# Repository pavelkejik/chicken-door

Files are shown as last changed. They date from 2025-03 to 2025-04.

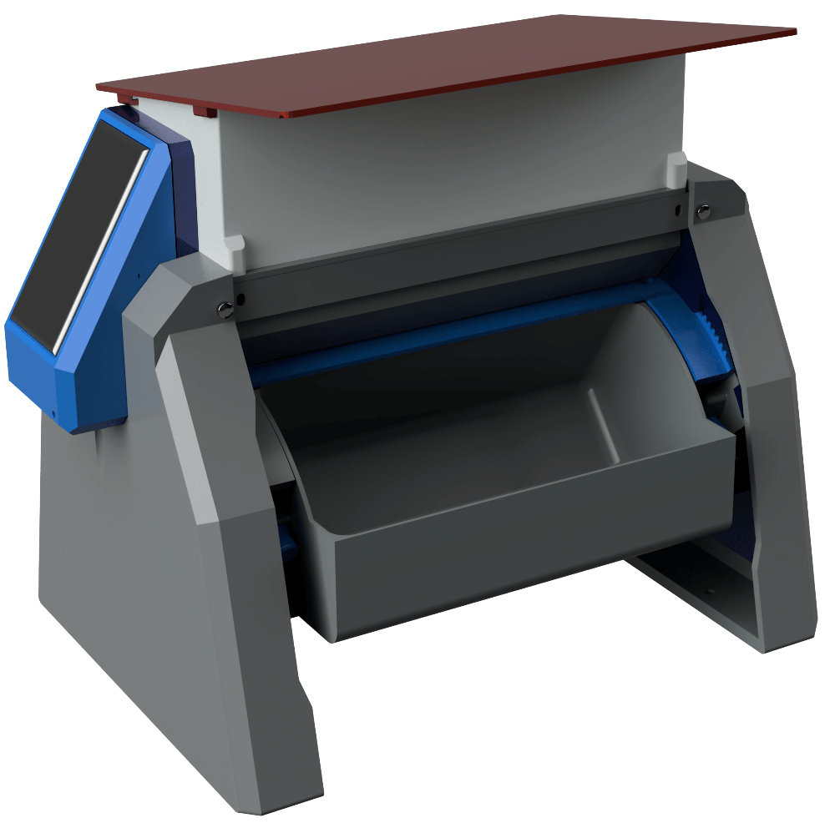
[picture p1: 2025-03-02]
web/src/assets/feeder.PNG

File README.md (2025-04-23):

# 🐔 Automated Chicken Coop Ecosystem  
_A modular IoT platform for stress-free backyard chicken keeping_

## Contents
1. [Project Overview](#project-overview)  
2. [Core Features](#core-features)  
3. [System Architecture](#system-architecture)  
4. [Hardware](#hardware)  
   1. [Chicken Door (Gateway)](#chicken-door-gateway)  
   2. [Accessories](#accessories)  
5. [Communication & APIs](#communication--apis)  
6. [Safety & Reliability](#safety--reliability)  
7. [Getting Started](#getting-started)  
8. [MQTT Quick Reference](#mqtt-quick-reference)  
9. [Roadmap](#roadmap)  

---

## Project Overview
The project automates everyday coop duties by combining a **smart sliding door**, a set of battery-powered **accessories** (feeder, camera, …) and a modern web UI.  
The door acts as the **gateway**: it drives the motor, pairs with accessories over low-power **ESP-NOW**, exposes a local **Web UI + HTTP API**, and bridges everything to standard **MQTT** and optional **Modbus RTU** for seamless Home-Assistant integration.

---

## Core Features
| Area | Highlights |
|---|---|
|Automation|• Auto-open/close by **sunrise/sunset** (astronomical) or **ambient light** plus configurable offsets  <br>• Full manual override via button, Web UI, MQTT, or Modbus|
|Safety|• Encoder-based position tracking, upper/lower limit calibration, soft-start/stop  <br>• Stall/over-current detection, timeout watchdog, emergency-stop state|
|Connectivity|• Wi-Fi STA/AP, **ESP-NOW** for accessories (1 km LR)  <br>• MQTT (via configurable `base_topic`), HTTP/REST, captive portal|
|Updates|• **OTA** firmware & file-system updates for door *and* every paired accessory through ESP-NOW|
|Accessories|• **Smart Feeder** – scheduled or weight-based servings  <br>• **Coop Camera** – still images on demand  <br>_Add your own!_  |
|Power|Door on 12 V DC; accessories battery-powered for months thanks to deep-sleep design|

---

## System Architecture
```
ESP32-S3 Door  ── Wi-Fi STA ⇆ Home Network ⇆ MQTT Broker / Home Assistant
      │
      ├─ Wi-Fi AP (for first-run config)
      └─ ESP-NOW P2P
             ├─ Feeder (ESP32-C3, battery)
             └─ Camera (ESP32-S3, battery)
```
Door firmware is C++/Arduino on FreeRTOS; the web interface is Vite + Vue 3 + Vuetify served directly from on-board **LittleFS**.

---

## Hardware
### Chicken Door (Gateway)
* **Drive**: 12 V DC gear-motor + rack-and-pinion (self-locking)  
* **MCU**: ESP32-S3-WROOM-1 (8 MB PSRAM)  
* **Sensors**: quadrature encoder, NTC temperature, photodiode (light)  
* **IO Expansion**: 2 GPIO inputs, open-collector output, RS-485 (Modbus RTU)  
* **Indicators**: bi-color status LED

### Accessories
| Name | Repo | Brief |
|---|---|---|
|Smart Feeder|<https://github.com/pavelkejik/chicken-feeder>|Servo-lid + load-cell; daily schedule or “feed-to-weight” mode|
|Coop Camera|<https://github.com/pavelkejik/chicken-camera>|ESP32-S3 w/ OV2640; images send over ESP-NOW|

Each accessory ships its own OTA-updatable firmware and pairs with one click via the Web UI. Status appears alongside the door dashboard.

---

## Communication & APIs
| Layer | Tech | Notes |
|---|---|---|
|Local Web UI|`http://dvirka.local` (mDNS) or captive portal |Full config, live telemetry, manual commands|
|REST/JSON|`/api/door`, `/api/accessory/{id}`|Same parameter map as MQTT|
|MQTT|`<base_topic>/state/...` and `/set/...` |Door & all accessories share a unified schema|
|Modbus RTU|RS-485, 9600 8N1 |Minimal register map for industrial PLCs|
|ESP-NOW|1 Mbit/s (500 kbit/s LR) |door = server, accessories = clients|

---

## Safety & Reliability
* **Hard limits + soft position** ensure gentle landings and no unexpected slams.  
* Every motion path is guarded by current & timeout watchdogs; any fault triggers _Emergency Stop_ with MQTT/HTTP event.  
* Door refuses to auto-close if position => `UNKNOWN` until next recalibration pass.  
* Accessories inherit door time-base and watchdog pings to detect battery loss.

---

## Getting Started
### 1. Flash Firmware
```bash
# Door
cd firmware/door
pio run -t upload         # USB
pio run -t uploadfs       # Web assets
# Feeder / Camera similar...
```

### 2. First Boot & Wi-Fi Join
1. Hold the door’s button >3 s → it starts `Dvirka` AP (both LEDs solid).  
2. Connect with a phone, open any page → captive portal shows config.  
3. Enter your SSID/PSK; the door reboots and joins STA mode.  

### 3. Build the Web UI Locally (optional)
```bash
cd web-ui
npm i
npm run dev
```

### 4. Pair Accessories
Open **Menu → Accessories → “New” → Pair** and press the accessory button once. State flips from _New_ → _Connected_.

---

## MQTT Quick Reference
```text
<base_topic>/state/position        = "OPEN" | "CLOSED" | "OPENING" | ...
<base_topic>/state/light_lux       = 123
<base_topic>/set/command           ← "OPEN" | "CLOSE" | "STOP"

<base_topic>/devices/<id>/state/weight_g
```
Replace `<base_topic>` in the Web UI.

---

## Roadmap
- [ ] Add waterer accessory
- [ ] Implement chicken presence counting using RFID tags   
- [x] Publish 3D-print STLs & KiCad sources

---

### Author
**Pavel Kejík**

> Built for my family’s coop, released for every backyard chicken keeper 🤘

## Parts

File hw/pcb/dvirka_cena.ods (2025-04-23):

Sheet: dvirka_cena
Id | Komponent | Označení | Pouzdro | Počet | MJ | Označení | Jednotková cena | cena
1 | DPS | J4 | Molex_KK-254_AE-6410-02A_1x02_P2.54mm_Vertical | 1 | ks | Conn_01x02_Pin | 5 | 5
2 | DPS | SW1 | SW_PUSH_6mm | 1 | ks | SW_Push | 9,91 | 9,91
3 | DPS | C15,C17,C16 | C_0805_2012Metric_Pad1.18x1.45mm_HandSolder | 3 | ks | 33pF | 1 | 3
4 | DPS | C20,C6,C7,C21,C18,C10,C9 | C_0805_2012Metric_Pad1.18x1.45mm_HandSolder | 7 | ks | 15nF | 1 | 7
5 | DPS | C12,C11,C19 | C_0805_2012Metric_Pad1.18x1.45mm_HandSolder | 3 | ks | 1nF | 1 | 3
6 | DPS | F1 | Fuse_2920_7451Metric_Pad2.10x5.45mm_HandSolder | 1 | ks | 0ZCF0100AF2A | 15 | 15
7 | DPS | R30,R18,R19 | R_0805_2012Metric_Pad1.20x1.40mm_HandSolder | 3 | ks | 10K | 0,8 | 2,4
8 | DPS | D6 | LED_D5.0mm-3 | 1 | ks | LED_Dual_AKA | 10 | 10
9 | DPS | D2,D5,D4,D3 | D_SOD-123F | 4 | ks | 1N4148WT | 1 | 4
10 | DPS | Q2,Q1 | SOT-23 | 2 | ks | BC846 | 0,7 | 1,4
11 | DPS | R16,R25,R24 | R_0805_2012Metric_Pad1.20x1.40mm_HandSolder | 3 | ks | 2K2 | 0,8 | 2,4
12 | DPS | R22,R21,R23 | R_0805_2012Metric_Pad1.20x1.40mm_HandSolder | 3 | ks | 100R | 0,8 | 2,4
13 | DPS | R26,R7,R27,R6 | R_0805_2012Metric_Pad1.20x1.40mm_HandSolder | 4 | ks | 470R | 0,8 | 3,2
14 | DPS | J3 | RJ45_Amphenol_54602-x08_Horizontal | 1 | ks | RJ45 | 15 | 15
15 | DPS | R13 | R_LDR_5.1x4.3mm_P3.4mm_Vertical | 1 | ks | R_Photo | 10 | 10
16 | DPS | U2,U5 | USON-10_2.5x1.0mm_P0.5mm | 2 | ks | TPD4E02B04DQA | 10 | 20
17 | DPS | R10,R11 | R_0805_2012Metric_Pad1.20x1.40mm_HandSolder | 2 | ks | 3R3 | 0,8 | 1,6
18 | DPS | U4 | SOIC-8_3.9x4.9mm_P1.27mm | 1 | ks | MAX485E | 50 | 50
19 | DPS | U3 | SOT-223-3_TabPin2 | 1 | ks | AMS1117-3.3 | 2 | 2
20 | DPS | R8,R20 | R_0805_2012Metric_Pad1.20x1.40mm_HandSolder | 2 | ks | 120R | 0,8 | 1,6
21 | DPS | IC1 | SOIC127P1420X360-21N | 1 | ks | L6201PS | 180 | 180
22 | DPS | U1 | ESP32-S3-WROOM-1 | 1 | ks | ESP32-S3-WROOM-1 | 87 | 87
23 | DPS | C1,C5,C14,C4 | C_0805_2012Metric_Pad1.18x1.45mm_HandSolder | 4 | ks | 100nF | 1 | 4
24 | DPS | C13,C22 | C_0805_2012Metric_Pad1.18x1.45mm_HandSolder | 2 | ks | 10uF | 1 | 2
25 | DPS | R12 | R_0805_2012Metric_Pad1.20x1.40mm_HandSolder | 1 | ks | 4K7 | 0,8 | 0,8
26 | DPS | R3,R17 | R_0805_2012Metric_Pad1.20x1.40mm_HandSolder | 2 | ks | 1M | 0,8 | 1,6
27 | DPS | R28 | R_0805_2012Metric_Pad1.20x1.40mm_HandSolder | 1 | ks | 68R | 0,8 | 0,8
28 | DPS | R29 | R_0805_2012Metric_Pad1.20x1.40mm_HandSolder | 1 | ks | 0R | 0,8 | 0,8
29 | DPS | J2 | PinHeader_1x06_P2.54mm_Vertical | 1 | ks | Conn_01x06_Socket | 2 | 2
30 | DPS | C8 | C_0805_2012Metric_Pad1.18x1.45mm_HandSolder | 1 | ks | 220nF | 1 | 1
31 | DPS | D1 | D_SMA | 1 | ks | ESDA18-1K | 1 | 1
32 | DPS | D7 | D_SOD-123F | 1 | ks | 1N4007 | 1 | 1
33 | DPS | R9,R1,R2 | R_0805_2012Metric_Pad1.20x1.40mm_HandSolder | 3 | ks | 5k1 | 0,8 | 2,4
34 | DPS | J5 | BarrelJack_Wuerth_694108106102_2.5x5.5mm | 1 | ks | Barrel_Jack_Switch | 21 | 21
35 | DPS | C2 | C_1206_3216Metric_Pad1.33x1.80mm_HandSolder | 1 | ks | 10u/50V |  | 0
36 | DPS | R15 | R_0805_2012Metric_Pad1.20x1.40mm_HandSolder | 1 | ks | 3K3 | 0,8 | 0,8
37 | DPS | R5,R4 | R_0805_2012Metric_Pad1.20x1.40mm_HandSolder | 2 | ks | 10R | 0,8 | 1,6
38 | DPS | C3,C23 | CP_Elec_6.3x7.7 | 2 | ks | 150uF/16V | 2,8 | 5,6
39 | DPS | K1 | Relay_SPST_StandexMeder_SIL_Form1A | 1 | ks | SILxx-1Axx-71x | 26 | 26
40 | DPS | TH1 | C_Disc_D3.8mm_W2.6mm_P2.50mm | 1 | ks | Thermistor_NTC | 8 | 8
41 | DPS | R14,R31 | R_0805_2012Metric_Pad1.20x1.40mm_HandSolder | 2 | ks | 100K | 0,8 | 1,6
42 | DPS | PS1 | K7805MT500R4 | 1 | ks | K7805MT-500R4 | 25 | 25
43 | DPS | J1 | USB_C_Receptacle_GCT_USB4105-xx-A_16P_TopMnt_Horizontal | 1 | ks | USB_C_Receptacle_USB2.0 | 21 | 21
44 | DPS | J9 | PinHeader_2x04_P2.54mm_Vertical | 1 | ks | Conn_02x04_Odd_Even | 2 | 2
45 | DPS | U7,U6,U9,U8 | TCST1103 | 2 | ks | TCST1103 | 24 | 48
46 | DPS | J8 | PinHeader_2x04_P2.54mm_Horizontal | 1 | ks | Conn_02x04_Odd_Even | 2 | 2
 | DPS |  | Dvoustranná deska PCB s maskou a potiskem, frézované okraje | 1 | ks |  | 100 | 100
 | Motor |  | DCROBOT | 1 | ks |  | 500 | 500
 | Wi-Fi antena |  | Wi-Fi antena | 1 | ks |  | 200 | 200
 | Pohonná jednotka |  | hřeben | 80 | g |  | 0,4 | 32
 | Pohonná jednotka |  |  | 3 | h |  | 0 | 0
 | Pohonná jednotka |  | držák motoru | 90 | g |  | 0,4 | 36
 | Pohonná jednotka |  |  | 4 | h |  | 0 | 0
 | Pohonná jednotka |  | Kryt venkovní | 200 | g |  | 0,4 | 80
 | Pohonná jednotka |  |  | 6 | h |  | 0 | 0
 | Pohonná jednotka |  | Kryt elektroniky | 61 | g |  | 0,4 | 24,4
 | Pohonná jednotka |  |  | 2 | h |  | 0 | 0
 | Pohonná jednotka |  | Pastorek | 12 | g |  | 0,4 | 4,8
 | Pohonná jednotka |  |  | 0,75 | h |  | 0 | 0
 | Pohonná jednotka |  | Paka a komponenty aretace | 40 | g |  | 0,4 | 16
 | Pohonná jednotka |  |  | 1,5 | h |  | 0 | 0
 | Pohonná jednotka |  | Dno | 47 | g |  | 0,4 | 18,8
 | Pohonná jednotka |  |  | 1 | h |  | 0 | 0
 | Pohonná jednotka |  | šrouby M4 | 1 | sada |  | 20 | 20
 | Pohonná jednotka |  | Pružiny | 4 | ks |  | 10 | 40
 | Prototyp dvířek |  | šrouby M4 | 1 | sada |  | 20 | 20
 | Prototyp dvířek |  | teleskopické kluzáky | 1 | dvojice |  | 70 | 70
 | Prototyp dvířek |  | Plastová dvířka | 240 | g |  | 0,4 | 96
 | Prototyp dvířek |  |  | 5 | h |  | 0 | 0
 | Prototyp dvířek |  | Plastové držáky | 280 | g |  | 0,4 | 112
 | Prototyp dvířek |  |  | 8 | h |  | 0 | 0
 |  |  |  |  |  |  |  | 1985,91

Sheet: Krmitko
Id | Komponent | Označení | Pouzdro | Počet | MJ | Označení | Jednotková cena | cena
1 | DPS | J7,J5 | Molex_KK-254_AE-6410-02A_1x02_P2.54mm_Vertical | 2 | ks | Conn_01x02_Pin | 5 | 10
2 | DPS | Q1 | SOT-23 | 1 | ks | BC807 | 0,6 | 0,6
3 | DPS | R19 | R_0805_2012Metric_Pad1.20x1.40mm_HandSolder | 1 | ks | 270K | 0,6 | 0,6
4 | DPS | R17 | R_0805_2012Metric_Pad1.20x1.40mm_HandSolder | 1 | ks | 5K | 0,6 | 0,6
5 | DPS | C18,C4,C17,C5,C24,C22,C23,C14,C10 | C_0805_2012Metric_Pad1.18x1.45mm_HandSolder | 9 | ks | 33pF | 0,7 | 6,3
6 | DPS | R3 | R_0805_2012Metric_Pad1.20x1.40mm_HandSolder | 1 | ks | 1M | 0,6 | 0,6
7 | Ostatní EL. Díly | J4 | Molex_KK-254_AE-6410-02A_1x02_P2.54mm_Vertical | 1 | ks | FV_Cell | 100 | 100
8 | DPS | R12 | R_0805_2012Metric_Pad1.20x1.40mm_HandSolder | 1 | ks | 1K | 0,6 | 0,6
9 | DPS | C25,C3,C2,C6,C13,C9 | C_0805_2012Metric_Pad1.18x1.45mm_HandSolder | 6 | ks | 10nF | 0,7 | 4,2
10 | DPS | D7 | D_SOD-123 | 1 | ks | B0520LW-7-F | 1 | 1
11 | DPS | R8 | R_0805_2012Metric_Pad1.20x1.40mm_HandSolder | 1 | ks | XR | 0,6 | 0,6
12 | DPS | U3 | SOP-16_3.9x9.9mm_P1.27mm | 1 | ks | HX711 | 10 | 10
13 | DPS | R13,R23,R20,R28,R14,R29 | R_0805_2012Metric_Pad1.20x1.40mm_HandSolder | 6 | ks | 100K | 0,6 | 3,6
14 | DPS | U2 | SOT-89-3 | 1 | ks | MCP1700x-330xxMB | 10 | 10
15 | DPS | R18,R7,R27,R25,R11,R2,R24,R6,R10 | R_0805_2012Metric_Pad1.20x1.40mm_HandSolder | 9 | ks | 100R | 0,6 | 5,4
16 | DPS | R4,R5 | R_0805_2012Metric_Pad1.20x1.40mm_HandSolder | 2 | ks | 5k1 | 0,6 | 1,2
17 | DPS | C21 | C_0805_2012Metric_Pad1.18x1.45mm_HandSolder | 1 | ks | 15nF | 0,7 | 0,7
18 | DPS | C7,C19,C1,C16,C15,C20,C11,C8 | C_0805_2012Metric_Pad1.18x1.45mm_HandSolder | 8 | ks | 10uF | 0,7 | 5,6
19 | DPS | R9 | R_0805_2012Metric_Pad1.20x1.40mm_HandSolder | 1 | ks | YR | 0,6 | 0,6
20 | DPS | REF** | Lightpipe_Mentor_1275.x00x | 1 | ks | Lightpipe_Mentor_1275.x00x | 37 | 37
21 | DPS | R1 | R_0805_2012Metric_Pad1.20x1.40mm_HandSolder | 1 | ks | 10K | 0,6 | 0,6
22 | DPS | F3 | Fuse_2920_7451Metric_Pad2.10x5.45mm_HandSolder | 1 | ks | 0ZCF0100AF2A | 15 | 15
23 | DPS | Q2 | SOT-23 | 1 | ks | AO3401A | 1 | 1
24 | DPS | J2 | USB_C_Receptacle_GCT_USB4105-xx-A_16P_TopMnt_Horizontal | 1 | ks | USB_C_Receptacle_USB2.0 | 20 | 20
25 | DPS | U5 | HTSSOP-16-1EP_4.4x5mm_P0.65mm_EP3.4x5mm_Mask2.46x2.31mm_ThermalVias | 1 | ks | DRV8833PWP | 60 | 60
26 | DPS | R22 | R_0805_2012Metric_Pad1.20x1.40mm_HandSolder | 1 | ks | 1R | 0,6 | 0,6
27 | DPS | SW2,SW1 | SW_Tactile_SPST_Angled_PTS645Vx58-2LFS | 2 | ks | SW_Push | 10 | 20
28 | DPS | C12 | CP_Elec_6.3x7.7 | 1 | ks | 100uF/16V | 4 | 4
29 | DPS | J1 | PinHeader_1x06_P2.54mm_Vertical | 1 | ks | Conn_01x06_Socket | 1 | 1
30 | DPS | D4 | D_SOD-123F | 1 | ks | 1N4148WT | 1 | 1
31 | DPS | R15,R16 | R_0805_2012Metric_Pad1.20x1.40mm_HandSolder | 2 | ks | 2K | 0,6 | 1,2
32 | DPS | U1 | ESP32-C3-MINI-1 | 1 | ks | ESP32-C3-MINI-1 | 50 | 50
33 | DPS | R21 | R_0805_2012Metric_Pad1.20x1.40mm_HandSolder | 1 | ks | 4K7 | 0,6 | 0,6
34 | DPS | D3 | D_SMA | 1 | ks | ESDA18-1K | 2 | 2
35 | DPS | D1 | LED_1210_3225Metric_Pad1.42x2.65mm_HandSolder | 1 | ks | LED | 4 | 4
36 | DPS | J6 | Molex_KK-254_AE-6410-04A_1x04_P2.54mm_Vertical | 1 | ks | Conn_01x04_Pin | 5 | 5
37 | DPS | R30 | R_0805_2012Metric_Pad1.20x1.40mm_HandSolder | 1 | ks | 0R | 0,6 | 0,6
38 | DPS | U4 | QFN-20-1EP_4x4mm_P0.5mm_EP2.5x2.5mm | 1 | ks | MCP73871-2AA | 45 | 45
39 | DPS | BT1 | BatteryHolder_MPD_BH-18650-PC2 | 1 | ks | Battery_18650 | 40 | 40
 | Ostatní EL. Díly |  | Baterie 18650 | 1 | ks |  | 70 | 70
 | DPS |  | Dvoustranná deska PCB s maskou a potiskem, frézované okraje | 1 | ks |  | 80 | 80
 | Ostatní EL. Díly |  | Motor | 2 | ks |  | 30 | 60
 | Ostatní EL. Díly |  | Tenzometrické čidlo | 2 | ks |  | 100 | 200
 | Ostatní EL. Díly |  | Koncové spínače | 2 | ks |  | 15 | 30
 | Ostatní EL. Díly |  | Vodiče + konektory | 1 | sada |  | 30 | 30
 | Mechanika |  | Bočnice kryt levý | 280 | g |  | 0,4 | 112
 | Mechanika |  |  | 7 | h |  | 0 | 0
 | Mechanika |  | Bočnice kryt pravý | 340 | g |  | 0,4 | 136
 | Mechanika |  |  | 8,5 | h |  | 0 | 0
 | Mechanika |  | Bočnice L | 210 | g |  | 0,4 | 84
 | Mechanika |  |  | 5 | h |  | 0 | 0
 | Mechanika |  | Bočnice P | 140 | g |  | 0,4 | 56
 | Mechanika |  |  | 3 | h |  | 0 | 0
 | Mechanika |  | Otočné segmenty | 180 | g |  | 0,4 | 72
 | Mechanika |  |  | 4 | h |  | 0 | 0
 | Mechanika |  | Záklopka | 100 | g |  | 0,4 | 40
 | Mechanika |  |  | 5 | h |  | 0 | 0
 | Mechanika |  | Rozvaděč | 140 | g |  | 0,4 | 56
 | Mechanika |  |  | 5 | h |  | 0 | 0
 | Mechanika |  | Násypka | 280 | g |  | 0,4 | 112
 | Mechanika |  |  | 7,5 | h |  | 0 | 0
 | Mechanika |  | Nádobka | 270 | g |  | 0,4 | 108
 | Mechanika |  |  | 8 | h |  | 0 | 0
 | Mechanika |  | Komponenty senzoru | 58 | g |  | 0,4 | 23,2
 | Mechanika |  |  | 2 | h |  | 0 | 0
 | Mechanika |  | Rozpěrné pásky | 96 | g |  | 0,4 | 38,4
 | Mechanika |  |  | 2,5 | h |  | 0 | 0
 | Mechanika |  | Násypka + stříška | 405 | g |  | 0,4 | 162
 | Mechanika |  |  | 10 | h |  | 0 | 0
 | Mechanika |  | Pastorek | 7 | g |  | 0,4 | 2,8
 | Mechanika |  |  | 0,5 | h |  | 0 | 0
 | Mechanika |  | šrouby a matice | 1 | sada |  | 100 | 100
 | Mechanika |  | Tyčka | 1 | ks |  | 30 | 30
 |  |  | Silikonové těsnění | 1 | ks |  | 30 | 30
 |  |  |  |  |  |  |  | 2103,2

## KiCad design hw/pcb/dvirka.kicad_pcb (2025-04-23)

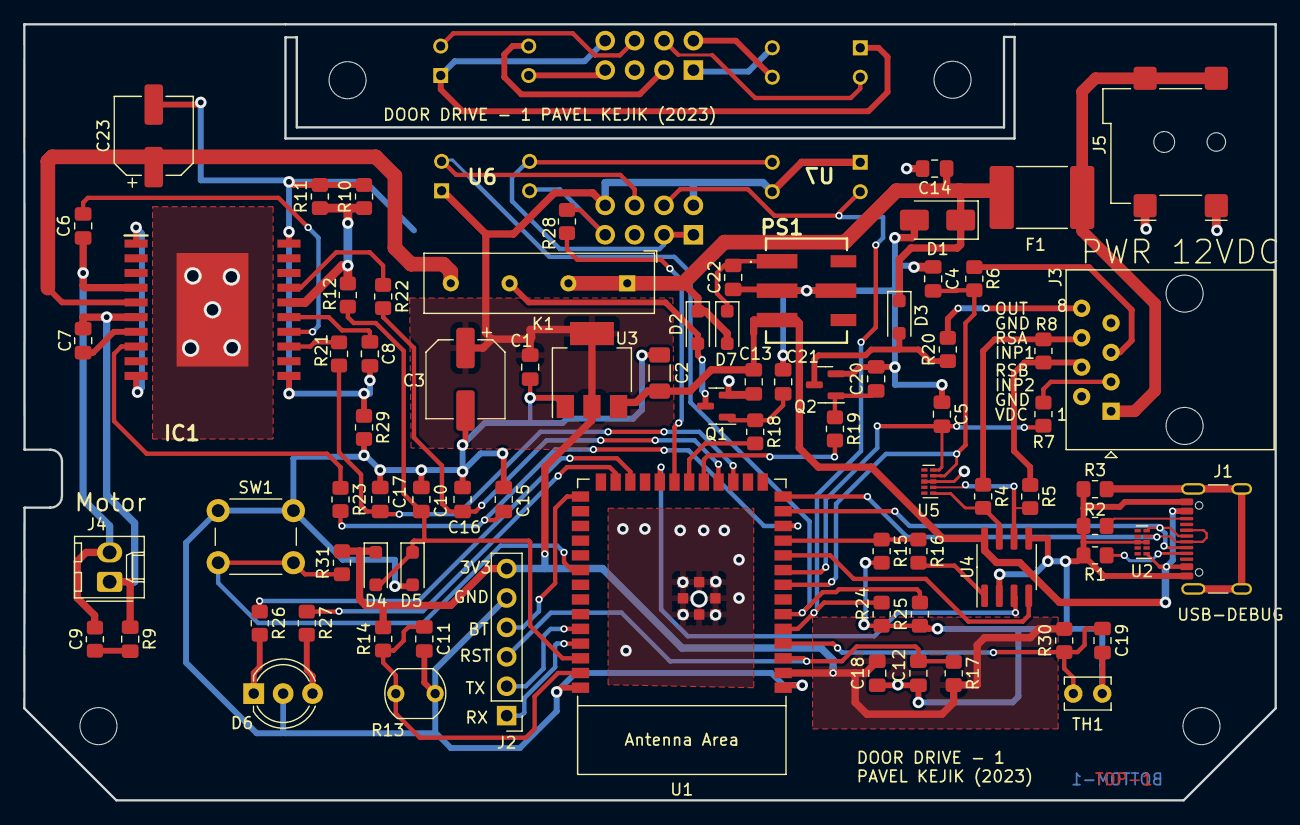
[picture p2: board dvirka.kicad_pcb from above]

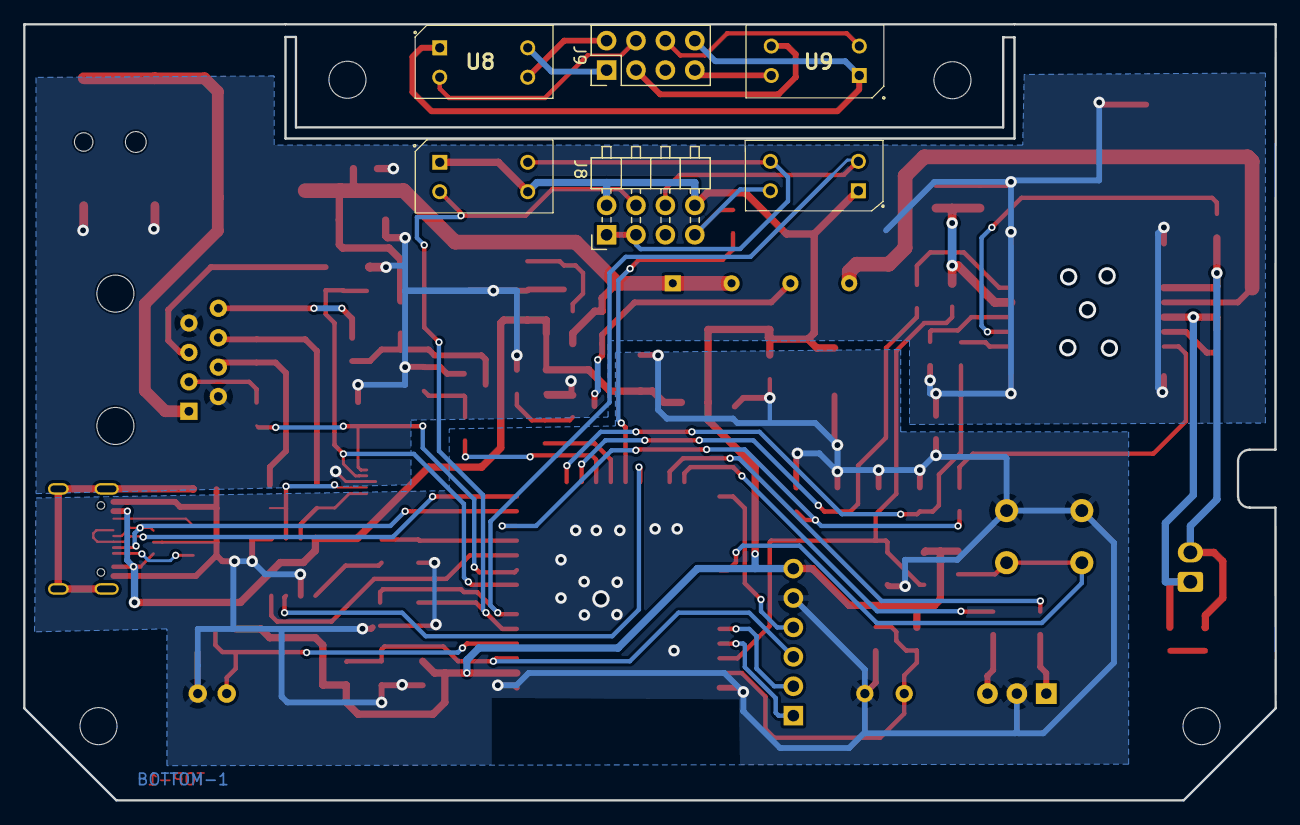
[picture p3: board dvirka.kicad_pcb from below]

Board: 2 copper layers, 108.1 x 67.0 mm, 85 parts (6 on the bottom side), 69 nets.

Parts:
C1, C4, C5, C14: 100nF; C_0805_2012Metric_Pad1.18x1.45mm_HandSolder
C2: 10u/50V; C_1206_3216Metric_Pad1.33x1.80mm_HandSolder
C3, C23: 150uF/16V; CP_Elec_6.3x7.7
C6, C7, C9, C10, C18, C20, C21: 15nF; C_0805_2012Metric_Pad1.18x1.45mm_HandSolder
C8: 220nF; C_0805_2012Metric_Pad1.18x1.45mm_HandSolder
C11, C12, C19: 1nF; C_0805_2012Metric_Pad1.18x1.45mm_HandSolder
C13, C22: 10uF; C_0805_2012Metric_Pad1.18x1.45mm_HandSolder
C15, C16, C17: 33pF; C_0805_2012Metric_Pad1.18x1.45mm_HandSolder
D1: ESDA18-1K; D_SMA
D2, D3, D4, D5: 1N4148WT; D_SOD-123F
D6: LED_Dual_AKA; LED_D5.0mm-3
D7: 1N4007; D_SOD-123F
F1: 0ZCF0100AF2A; Fuse_2920_7451Metric_Pad2.10x5.45mm_HandSolder
IC1: L6201PS; SOIC127P1420X360-21N
J1: USB_C_Receptacle_USB2.0; USB_C_Receptacle_GCT_USB4105-xx-A_16P_TopMnt_Horizontal
J2: Conn_01x06_Socket; PinHeader_1x06_P2.54mm_Vertical
J3: RJ45; RJ45_Amphenol_54602-x08_Horizontal
J4: Conn_01x02_Pin; Molex_KK-254_AE-6410-02A_1x02_P2.54mm_Vertical
J5: Barrel_Jack_Switch; BarrelJack_Wuerth_694108106102_2.5x5.5mm
J8: Conn_02x04_Odd_Even; PinHeader_2x04_P2.54mm_Horizontal
J9: Conn_02x04_Odd_Even; PinHeader_2x04_P2.54mm_Vertical
K1: SILxx-1Axx-71x; Relay_SPST_StandexMeder_SIL_Form1A
PS1: K7805MT-500R4; K7805MT500R4
Q1, Q2: BC846; SOT-23
R1, R2, R9: 5k1; R_0805_2012Metric_Pad1.20x1.40mm_HandSolder
R3, R17: 1M; R_0805_2012Metric_Pad1.20x1.40mm_HandSolder
R4, R5: 10R; R_0805_2012Metric_Pad1.20x1.40mm_HandSolder
R6, R7, R26, R27: 470R; R_0805_2012Metric_Pad1.20x1.40mm_HandSolder
R8, R20: 120R; R_0805_2012Metric_Pad1.20x1.40mm_HandSolder
R10, R11: 3R3; R_0805_2012Metric_Pad1.20x1.40mm_HandSolder
R12: 4K7; R_0805_2012Metric_Pad1.20x1.40mm_HandSolder
R13: R_Photo; R_LDR_5.1x4.3mm_P3.4mm_Vertical
R14, R31: 100K; R_0805_2012Metric_Pad1.20x1.40mm_HandSolder
R15: 3K3; R_0805_2012Metric_Pad1.20x1.40mm_HandSolder
R16, R24, R25: 2K2; R_0805_2012Metric_Pad1.20x1.40mm_HandSolder
R18, R19, R30: 10K; R_0805_2012Metric_Pad1.20x1.40mm_HandSolder
R21, R22, R23: 100R; R_0805_2012Metric_Pad1.20x1.40mm_HandSolder
R28: 68R; R_0805_2012Metric_Pad1.20x1.40mm_HandSolder
R29: 0R; R_0805_2012Metric_Pad1.20x1.40mm_HandSolder
SW1: SW_Push; SW_PUSH_6mm
TH1: Thermistor_NTC; C_Disc_D3.8mm_W2.6mm_P2.50mm
U1: ESP32-S3-WROOM-1
U2, U5: TPD4E02B04DQA; USON-10_2.5x1.0mm_P0.5mm
U3: AMS1117-3.3; SOT-223-3_TabPin2
U4: MAX485E; SOIC-8_3.9x4.9mm_P1.27mm
U6, U7, U8, U9: TCST1103

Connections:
+3.3V: C1.1, C3.1, C18.2, D4.1 (K), J2.6, J8.2, J8.8, R14.2, R17.2, R30.2, R31.2, U1.2 (3V3), U3.2 (VO), U6.1 (+_1), U7.1 (+_1), U7.3 (+_2)
+5V: C2.1, C13.1, J1.A4 (VBUS), J1.A9 (VBUS), J1.B4 (VBUS), J1.B9 (VBUS), PS1.3 (+VO), U2.1 (IO1), U3.3 (VI), U4.8 (VCC)
+12V: C14.1, D1.1 (K), D2.1 (K), D3.1 (K), D7.2 (A), F1.2, K1.1, K1.3
AINP_MOT: C10.2, D4.2 (A), D5.1 (K), R12.1, U1.38 (GPIO2/TOUCH2/ADC1_CH1)
AINP_PHOTO: C11.1, R13.1, R14.1, U1.39 (GPIO1/TOUCH1/ADC1_CH0)
AINP_THERM: C19.1, R30.1, TH1.1, U1.4 (GPIO4/TOUCH4/ADC1_CH3)
AUXOUT: J3.8, R20.2
BOOT: J2.4, U1.27 (GPIO0/BOOT)
DE485: U1.22 (GPIO14/TOUCH14/ADC2_CH3/FSPIWP/FSPIDQS/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), U4.3 (DE)
DEBUG_RX: J2.1, U1.37 (U0TXD/GPIO43/CLK_OUT1)
DEBUG_TX: J2.2, U1.36 (U0RXD/GPIO44/CLK_OUT2)
GND: C1.2, C2.2, C3.2, C10.1, C11.2, C12.1, C15.2, C16.2, C17.1, C18.1, C19.2, D5.2 (A), D6.2 (K), J1.A1 (GND), J1.A12 (GND), J1.B1 (GND), J1.B12 (GND), J2.5, R1.2, R2.2, R3.1, R13.2, R15.2, R24.1, R25.1, R29.2, SW1.1, TH1.2, U1.1 (GND), U1.40 (GND), U1.41 (GND), U2.3 (G), U2.8 (G), U3.1 (GND), U4.2 (~RE), U4.5 (GND)
GNDPWR: C4.1, C5.1, C8.1, C13.2, C14.2, C20.2, C21.2, C22.2, C23.2, D1.2 (A), IC1.1 (GND_1), IC1.10 (GND_2), IC1.11 (GND_3), IC1.20 (GND_4), J3.2, J3.7, J5.1, PS1.2 (GND_1), PS1.5 (GND_2), Q1.2 (E), Q2.2 (E), R10.2, R11.2, R29.1, U5.3 (G), U5.8 (G)
INP1: C4.2, R6.2, U1.8 (GPIO15/U0RTS/ADC2_CH4/XTAL_32K_P), U5.4 (IO3)
INP2: C5.2, R7.2, U1.9 (GPIO16/U0CTS/ADC2_CH5/XTAL_32K_N), U5.5 (IO4)
INP_ENCA: J8.4, R24.2, U1.5 (GPIO5/TOUCH5/ADC1_CH4), U7.2 (E)
INP_ENCB: J8.6, R25.2, U1.6 (GPIO6/TOUCH6/ADC1_CH5), U6.2 (E)
MOT_PWR: C23.1, IC1.5 (VS), K1.7
unnamed: C9.1, R9.2
unnamed: D2.2 (A), K1.5, Q1.3 (C)
unnamed: D3.2 (A), Q2.3 (C), R20.1
unnamed: D6.1 (A1), R26.2
unnamed: D6.3 (A2), R27.2
unnamed: C22.1, D7.1 (K), PS1.1 (+VIN)
unnamed: C7.2, IC1.7 (BOOT1)
unnamed: C6.2, IC1.14 (BOOT2)
unnamed: IC1.17 (ENABLE), R22.1
unnamed: IC1.8 (IN1), R23.1
unnamed: IC1.13 (IN2), R21.1
unnamed: C7.1, C9.2, IC1.6 (OUT1), J4.1
unnamed: C6.1, IC1.4 (OUT2), J4.2, R9.1
unnamed: IC1.16 (SENSE), R10.1, R11.1, R12.2
unnamed: C8.2, IC1.15 (VREF)
unnamed: J1.A5 (CC1), R1.1
unnamed: J1.B5 (CC2), R2.1
unnamed: J1.S1 (SHIELD), R3.2
unnamed: J3.3, R7.1
unnamed: J3.4, R5.1, R8.2
unnamed: J3.5, R6.1
unnamed: J3.6, R4.1, R8.1
unnamed: J8.1, J8.3, U6.3 (+_2), U7.4 (D)
unnamed: J8.7, R28.2, U6.4 (D)
unnamed: J9.1, U8.4 (D)
unnamed: J9.2, U8.3 (+_2)
unnamed: J9.3, U9.3 (+_2)
unnamed: J9.4, U8.2 (E)
unnamed: J9.6, U9.2 (E)
unnamed: J9.7, U9.4 (D)
unnamed: J9.8, U8.1 (+_1), U9.1 (+_1)
unnamed: C21.1, Q1.1 (B), R18.1
unnamed: C20.1, Q2.1 (B), R19.1
unnamed: R31.1, SW1.2, U1.32 (MTCK/GPIO39/CLK_OUT3/SUBSPICS1)
unnamed: R5.2, U4.6 (A), U5.2 (IO2)
unnamed: R4.2, U4.7 (B), U5.1 (IO1)
unnamed: R16.2, U4.1 (RO)
OUT_AUXOUT: R19.2, U1.19 (GPIO11/TOUCH11/ADC2_CH0/FSPID/FSPIIO5/S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)
OUT_ENC: R28.1, U1.21 (GPIO13/TOUCH13/ADC2_CH2/FSPIQ/FSPIIO7/S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)
OUT_LEDG: R27.1, U1.25 (GPIO48/SPICLK_N/SUBSPICLK_N_DIFF)
OUT_LEDR: R26.1, U1.24 (GPIO47/SPICLK_P/SUBSPICLK_P_DIFF)
OUT_MOT1: C15.1, R23.2, U1.12 (GPIO8/TOUCH8/ADC1_CH7/SUBSPICS1)
OUT_MOT2: C17.2, R21.2, U1.17 (GPIO9/TOUCH9/ADC1_CH8/FSPIHD/SUBSPIHD)
OUT_MOT_EN: C16.1, R22.2, U1.18 (GPIO10/TOUCH10/ADC1_CH9/FSPICS0/FSPIIO4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)
OUT_MOT_PWR: R18.2, U1.20 (GPIO12/TOUCH12/ADC2_CH1/FSPICLK/FSPIIO6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)
RESET: C12.2, J2.3, R17.1, U1.3 (EN)
RXD485: R15.1, R16.1, U1.11 (GPIO18/U1RXD/ADC2_CH7/CLK_OUT3)
TXD485: U1.10 (GPIO17/U1TXD/ADC2_CH6), U4.4 (DI)
USBDATA+: J1.A6 (D+), J1.B6 (D+), U1.14 (GPIO20/U1CTS/ADC2_CH9/CLK_OUT1/USB_D+), U2.4 (IO3)
USBDATA-: J1.A7 (D-), J1.B7 (D-), U1.13 (GPIO19/U1RTS/ADC2_CH8/CLK_OUT2/USB_D-), U2.5 (IO4)
VDC: F1.1, J3.1, J5.2, J5.3

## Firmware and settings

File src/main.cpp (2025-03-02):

/***********************************************************************
 * Filename: main.cpp
 * Author: Pavel Kejik
 * Date: 2024-04-12
 * Description:
 *     This file serves as the entry point for the application, 
 *     setting up and managing all hardware and software components. 
 *     It initializes modules such as Modbus, MQTT, ESP-NOW, and WiFi 
 *     control, as well as handling device management, logging, and 
 *     web server operations. The program controls various tasks for 
 *     door and light management, system logging, and sensor data 
 *     monitoring, incorporating extensive use of FreeRTOS for task 
 *     management.
 *
 ***********************************************************************/


#include <Arduino.h>
#include <HardwareSerial.h>
#include "modbus_serial.h"
#include "modbus_slave.h"
#include "semphr.h"
#include "servo.h"
#include "pin_map.h"
#include "parameters.h"
#include "error.h"
#include "button.h"
#include "log.h"
#include "led.h"
#include "door_ctrl.h"
#include "light_ctrl.h"
#include "common.h"
#include <esp_now.h>
#include <WiFi.h>
#include "wifi_ctrl.h"
#include "locations.h"
#include "esp32s3/rom/rtc.h"
#include <LittleFS.h>
#include <DNSServer.h>
#include "web_server.h"
#include "esp_ota_ops.h"
#include "device_manager.h"
#include "mqtt.h"

ModbusSerial mdbSerial;
ModbusSlave mdbSlave(mdbSerial);
Motor motor(MOTOR_UP, MOTOR_DOWN, MOTOR_EN, 0);
Encoder encoder(ENCODER_A, ENCODER_B, ENCODER_PWR);
Servo servo(motor, encoder);
Button btn(BTN, INPUT);
Led LedR(LED_R);
Led LedG(LED_G);
LightCtrl lightCtrl;

int i = 0;
int j = 0;

const char *const reset_reason_txt[] = {
    "Poweron",
    "Software",
    "Watchdog",
    "Brownout",
    "External"};

void ModbusTask(void *pvParameters)
{
  while (true)
  {
    mdbSlave.Run();
    delay(1);
  }
}

void ServoTask(void *pvParameters)
{
  while (true)
  {
    servo.Run();
    delay(10);
  }
}

void EncoderTask(void *pvParameters)
{
  while (true)
  {
    encoder.Read();
    delay(ENCODER_SAMPLE_PERIOD_MS);
  }
}

void DoorControlTask(void *pvParameters)
{
  while (true)
  {
    DoorCtrl::Task();
    servo.Ctrl();
    delay(CONTROL_TASK_PERIOD_MS);
  }
}

void LedControlTask(void *pvParameters)
{
  while (true)
  {
    if (WiFiAPOn.Get())
    {
      if (WiFi.softAPgetStationNum() > 0)
      {
        LedR = 0;
        LedG = 0xFFFF;
      }
      else
      {
        LedR = 0xFFFF;
        LedG = 0xFFFF;
      }
    }
    else
    {
      switch (StavDvirka.Get())
      {
      case NeznaznamaPoloha:
        LedR = 0xF0F0;
        LedG = 0xF0F0;
        break;
      case Otevirani:
      case Zavirani:
      case UvolneniOtevirani:
      case UvolneniZavirani:
        LedG = 0x5555;
        LedR = 0;
        break;
      case OteviraniMax:
      case ZaviraniMin:
        LedG = 0x5555;
        LedR = 5;
        break;
      case Otevreno:
      case Zavreno:
        LedG = 0;
        LedR = 0;
        break;
      case PreruseniOtevirani:
      case PreruseniZavirani:
        LedG = 0x0f;
        LedR = 0x0f;
        break;
      case MeziPoloha:
      case StopZavirani:
      case StopOtevirani:
        LedG = 0xF00F;
        LedR = 0;
        break;
      case ChybaDveri:
        LedG = 0;
        LedR = 0xffff;
        break;
      default:
        break;
      }
    }
    LedR.CtrlTask();
    LedG.CtrlTask();
    delay(LED_CTRL_TIME_MS);
  }
}

void TimeControlTask(void *pvParameters)
{
  while (true)
  {
    lightCtrl.Task();
    Location::CheckLocalization();
    delay(AUTO_DETECTION_TASK_PERIOD_S * 1000);
  }
}

void WiFiControlTask(void *pvParameters)
{
  while (true)
  {
    WiFiCtrl::Task();
    delay(WIFI_CONTROL_TASK_PERIOD_MS);
  }
}

void MQTTTask(void *pvParameters)
{
  while (true)
  {
    MQTT::Task();
    delay(MQTT_TASK_PERIOD_MS);
  }
}

void AccessLvlTask(void)
{
  static uint32_t access_timer;
  if (AccessLvl.Get() == Servis)
  {
    if (millis() > (access_timer + 10 * 60 * 1000))
    {
      access_timer = millis();
      AccessLvl.Set(Uzivatel);
      Register::ActiveLevel = Par_Public;
    }
    else
    {
      AccessLvl.Set(Servis);
      Register::ActiveLevel = Par_Installer;
    }
  }
  else
  {
    access_timer = millis();
    AccessLvl.Set(Uzivatel);
    Register::ActiveLevel = Par_Public;
  }
}

void SystemLogTask(void *pvParameters)
{
  while (true)
  {
    SystemLog::Task();

    Uptime.Set((int32_t)(esp_timer_get_time() / 1000000ULL));
    PsramUsed.Set(PsramSize.Get() - (ESP.getFreePsram() / 1024));
    HeapUsed.Set(HeapSize.Get() - (ESP.getFreeHeap() / 1024));

    AccessLvlTask();

    delay(2000);
  }
}

void DataChartTask(void *pvParameters)
{
  delay(10 * 1000);
  while (true)
  {
    Teplota24H.Set(Teplota_C.Get());
    Svetlo24H.Set(Osvetleni_proc.Get());
    delay(3 * 60 * 1000);
  }
}

void ESPNowTask(void *pvParameters)
{
  while (true)
  {
    ESPNowCtrl::Task();
  }
}

void IRAM_ATTR onTimer()
{
  encoder.Read();
}

void setup()
{
  Serial.begin(115200);

  Register::InitAll();
  storageFS.begin(true, "/storage", 5, "storage");

  Svetlo24H.SetSize(512);
  Teplota24H.SetSize(512);

  mdbSlave.Init();
  servo.Init();
  encoder.SetPosition(AktualniPoloha_puls.Get());

  SystemLog::Init();
  Error::ClearAll();
  btn.Init();
  LedR.Init();
  LedG.Init();
  DoorCtrl::Init();
  Location::Init();
  lightCtrl.Init();
  WiFiCtrl::Init();
  WebServer::Init(CaptivePortal.Get() == povoleno);
  ESPNowCtrl::Init();
  DeviceManager::Init();
  MQTT::Init();

  SDKVersion.Set(ESP.getSdkVersion());
  HeapSize.Set(ESP.getHeapSize() / 1024);
  HeapUsed.Set(HeapSize.Get() - (ESP.getFreeHeap() / 1024));
  FlashSize.Set(ESP.getFlashChipSize() / 1024);
  FlashSpeed.Set(ESP.getFlashChipSpeed() / 1000000);
  CPUFreq.Set(ESP.getCpuFreqMHz());
  PsramSize.Set(ESP.getPsramSize() / 1024);
  PsramUsed.Set(PsramSize.Get() - (ESP.getFreePsram() / 1024));
  APPSize.Set((esp_ota_get_running_partition()->size / 1024));
  APPUsed.Set(ESP.getSketchSize() / 1024);
  FSSize.Set(storageFS.totalBytes() / 1024);
  FSUsed.Set(storageFS.usedBytes() / 1024);
  Uptime.Set((int32_t)(esp_timer_get_time() / 1000000ULL));
  CompDate.Set(COMPILE_DATE_TIME);

  switch (rtc_get_reset_reason(0))
  {
  case 1:
    ResetReason.Set(rst_Poweron);
    break;
  case 3:
  case 12:
    ResetReason.Set(rst_Software);
    break;
  case 4:
  case 7:
  case 8:
  case 9:
  case 11:
  case 13:
  case 16:
    ResetReason.Set(rst_Watchdog);
    break;
  case 15:
    ResetReason.Set(rst_Brownout);
    break;

  case 14:
    ResetReason.Set(rst_External);

  default:
    ResetReason.Set(rst_Unknown);
  }

  String start_txt = ">>> Start: [Hostname: " + WiFihostname.Get();
  start_txt += "] | Verze: " + String(MainRev.Get()) + " <<<";

  SystemLog::PutLog(start_txt.c_str(), v_empty);

  start_txt = "Kompilace: " + CompDate.Get();
  start_txt += " | Reset: " + String(reset_reason_txt[ResetReason.Get()]) + " (" + String(rtc_get_reset_reason(0)) + ")";

  SystemLog::PutLog(start_txt.c_str(), v_empty);

  xTaskCreateUniversal(ModbusTask, "mdbTask", getArduinoLoopTaskStackSize(), NULL, 1, NULL, -1);
  xTaskCreateUniversal(EncoderTask, "encoderTask", getArduinoLoopTaskStackSize(), NULL, 3, NULL, ARDUINO_RUNNING_CORE);
  xTaskCreateUniversal(ServoTask, "servoTask", getArduinoLoopTaskStackSize(), NULL, 3, NULL, ARDUINO_RUNNING_CORE);
  xTaskCreateUniversal(DoorControlTask, "doorCtrlTask", getArduinoLoopTaskStackSize(), NULL, 2, NULL, ARDUINO_RUNNING_CORE);
  xTaskCreateUniversal(LedControlTask, "ledCtrlTask", getArduinoLoopTaskStackSize(), NULL, 1, NULL, ARDUINO_RUNNING_CORE);
  xTaskCreateUniversal(TimeControlTask, "timeCtrlTask", getArduinoLoopTaskStackSize(), NULL, 1, NULL, ARDUINO_RUNNING_CORE);
  xTaskCreateUniversal(WiFiControlTask, "wifiTask", getArduinoLoopTaskStackSize(), NULL, 1, NULL, -1);
  xTaskCreateUniversal(SystemLogTask, "logTask", getArduinoLoopTaskStackSize(), NULL, 1, NULL, ARDUINO_RUNNING_CORE);
  xTaskCreateUniversal(DataChartTask, "chartTask", getArduinoLoopTaskStackSize(), NULL, 1, NULL, ARDUINO_RUNNING_CORE);
  xTaskCreateUniversal(ESPNowTask, "espNowTask", getArduinoLoopTaskStackSize(), NULL, 2, NULL, 0);
  xTaskCreateUniversal(MQTTTask, "mqttTask", getArduinoLoopTaskStackSize(), NULL, 1, NULL, -1);

  // hw_timer_t *timer = NULL;
  // // inicializace časovače
  // timer = timerBegin(0, 80, true);
  // timerAttachInterrupt(timer, &onTimer, true);
  // timerAlarmWrite(timer, ENCODER_SAMPLE_PERIOD_MS * 1000, true);
  // timerAlarmEnable(timer);
}

void loop()
{
  delay(COMMON_LOOP_TASK_PERIOD_MS);
  WebServer::Task();
  DeviceManager::Task();
  btn.Read();

  if (btn.IsOnEvent())
  {
    switch (StavDvirka.Get())
    {
    case Otevreno:
    case PreruseniZavirani:
    case NeznaznamaPoloha:
    case MeziPoloha:

      DoorCtrl::EventSourced(ev_close, povel_tlacitkem);
      break;

    case Zavreno:
    case PreruseniOtevirani:
      DoorCtrl::EventSourced(ev_open, povel_tlacitkem);
      break;

    default:
      DoorCtrl::Event(ev_stop);
      break;
    }
  }

  if (btn.IsLongOnEvent())
  {
    WiFiAPOn.Set(WiFiAPOn.Get() ? 0 : 1);
  }
}

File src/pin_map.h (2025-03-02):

/***********************************************************************
 * Filename: pin_map.h
 * Author: Pavel Kejik
 * Date: 2024-04-12
 * Description:
 *     Defines pin mappings for various components like RS485 communication,
 *     motor control, encoder inputs, and sensors.
 *
 ***********************************************************************/


#pragma once

#define DE485 14
#define TXD485 17
#define RXD485 18
#define RS485_SERIAL_PORT 1
#define MOTOR_UP 9
#define MOTOR_DOWN 8
#define MOTOR_EN 10
#define MOTOR_RELAY 12
#define MOTOR_ISENSE 2
#define ENCODER_PWR 13
#define ENCODER_A 5 // Encoder on the left
#define ENCODER_B 6 // Encoder on the right
#define BTN 39
#define LED_R 47
#define LED_G 48
#define PHOTO_R 1
#define TEMP_R 4

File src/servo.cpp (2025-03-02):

/***********************************************************************
 * Filename: servo.cpp
 * Author: Pavel Kejik
 * Date: 2024-04-12
 * Description:
 *     Implements the classes declared in servo.h.
 *
 ***********************************************************************/

#include "Arduino.h"
#include "common.h"
#include "servo.h"
#include "pin_map.h"
#include "parameters.h"

#define R_UP 10.0f
#define VCC 3280.0f
#define SHA_R25 10.0f
#define SHA_B 4150.0f
#define SHA_a0 (1.0f / (25 + 273.15))
#define SHA_a1 (1.0f / SHA_B)

void Encoder::Init(void)
{
	pinMode(pinE, OUTPUT);
	pinMode(pinA, INPUT);
	pinMode(pinB, INPUT);
}

void Encoder::SensorPwr(bool pwr)
{
	digitalWrite(pinE, pwr ? LOW : HIGH);
}

int16_t Encoder::Read()
{
	static bool lastchA = false;
	static bool lastchB = false;
	static uint16_t debStateCnt = 0;
	static int8_t lastDir;
	int8_t actDir;
	bool chA = digitalRead(pinA);
	bool chB = digitalRead(pinB);

	if (chA == lastchA && chB == lastchB)
	{
		if (debStateCnt < ENCODER_SAMPLE_DEBOUNCE_CNT)
		{
			debStateCnt++;
			if (debStateCnt == ENCODER_SAMPLE_DEBOUNCE_CNT)
			{
				encInp.chA = lastchA;
				encInp.chB = lastchB;
			}
		}
	}
	else
	{
		debStateCnt = 0;
		lastchA = chA;
		lastchB = chB;
	}

	// Sequence 2->0->1->3 when moving upwards
	// Sequence 3->1->0->2 when moving downwards
	// enc A is the lower bit, enc B is the upper bit
	if (encInp.chA != encInp.lastchA)
	{
		if (encInp.chA == encInp.chB)
		{
			position--;
		}
		else
		{
			position++;
		}
		debLimMax.Inp(!encInp.chB);
		encInp.lastchA = encInp.chA;
	}

	if (encInp.chB != encInp.lastchB)
	{
		if (encInp.chA == encInp.chB)
		{
			position++;
		}
		else
		{
			position--;
		}
		debLimMin.Inp(!encInp.chA);
		encInp.lastchB = encInp.chB;
	}

	if (abs(lastPos - position) > 2)
	{
		int32_t tmp = (position - lastPos) * VELOCITY_CONF_MM_S;
		tmp = (actSpeed + tmp) / 2;
		actSpeed = tmp / steadyTime;
		lastPos.store(position.load());
		steadyTime = 0;
	}
	else if (IsSteady())
	{
		actSpeed = 0;
	}
	else
	{
		steadyTime += ENCODER_SAMPLE_PERIOD_MS;
	}

	return position;
}

bool Encoder::IsSteady(void)
{
	return steadyTime > MAX_STEADY_TIME;
}

void Encoder::SetPosition(int16_t pos)
{
	lastPos = pos;
	position = pos;
}

int16_t Encoder::GetPosition(void)
{
	return position;
}

int16_t Encoder::GetActSpeed()
{
	return actSpeed;
}

void Motor::Init(void)
{
	pinMode(pinDown, OUTPUT);
	pinMode(pinUp, OUTPUT);
	pinMode(pinEn, OUTPUT);

	digitalWrite(pinDown, LOW);
	digitalWrite(pinUp, LOW);
	ledcSetup(pwmCH, PWM_FREQ_HZ, 8);
	ledcAttachPin(pinEn, 0);
	ledcWrite(pwmCH, 0);

	Run(0);
}

void Motor::Run(int16_t rate)
{
	int16_t tmp = rate;
	tmp = tmp * 255;
	tmp = tmp / 100;

	if (rate > 0)
	{
		if (tmp > 255)
		{
			tmp = 255;
		}
		digitalWrite(pinUp, HIGH);
		digitalWrite(pinDown, LOW);
		ledcWrite(pwmCH, tmp);
	}
	else if (rate < 0)
	{
		tmp = -tmp;
		if (tmp > 255)
		{
			tmp = 255;
		}
		digitalWrite(pinUp, LOW);
		digitalWrite(pinDown, HIGH);
		ledcWrite(pwmCH, tmp);
	}
	else
	{
		tmp = 0;
		digitalWrite(pinUp, LOW);
		digitalWrite(pinDown, LOW);
		ledcWrite(pwmCH, tmp);
	}
}

void Servo::InitMotorCtrl(void)
{
	pinMode(MOTOR_RELAY, OUTPUT);
	digitalWrite(MOTOR_RELAY, LOW);
}

void Servo::ReadCurrent(void)
{
	int32_t curr = analogReadMilliVolts(MOTOR_ISENSE) * 100 / 165;
	AktualniProud_mA.Set(current.Input(curr));
}

void Servo::ReadTemperature(void)
{
	temp_mv.Input(analogReadMilliVolts(TEMP_R));
}

int16_t Servo::GetTemperature(void)
{
	float resT = VCC / temp_mv.Out() - 1;
	resT = R_UP / resT;
	resT = 1 / (SHA_a0 + SHA_a1 * logf(resT / SHA_R25)) - 273.15;

	return (int16_t)resT;
}

void Servo::IsOverCurrentUp(int16_t current_ma)
{
	int16_t pwm = abs(RizeniMotoru_PWM.Get());
	if (pwm >= 0 && pwm < 40)
	{
		pwm = 40;
	}

	int32_t limit = (int32_t)MotorProudOtMax.Get() * pwm;
	limit /= 100;
	ovrl_up.Check(current_ma > limit);
	fast_ovrl_up.Check(current_ma > (int16_t)(OVERCURRENT_FAST(limit)));
}

void Servo::IsOverCurrentDown(int16_t current_ma)
{
	int16_t pwm = abs(RizeniMotoru_PWM.Get());
	if (pwm >= 0 && pwm < 40)
	{
		pwm = 40;
	}

	int32_t limit = (int32_t)MotorProudOtMin.Get() * pwm;
	limit /= 100;
	ovrl_down.Check(current_ma > limit);
	fast_ovrl_down.Check(current_ma > (int16_t)(OVERCURRENT_FAST(limit)));
}

void Servo::Init(void)
{
	isStopped = true;
	motor.Init();
	sensor.Init();
	InitMotorCtrl();
	sensor.SensorPwr(true);
	PidSpeed.Setparam(PIDRychlostP.Get(), PIDRychlostI.Get());
	PidSpeed.Outrange(-MAX_SPEED_CONST, MAX_SPEED_CONST, -45, 50);
	PidPosition.Setparam(PIDPolohaP.Get(), 0);
	PidPosition.Outrange(-MaxRychlost.Get(), MaxRychlost.Get(), -MinRychlost.Get(), MinRychlost.Get());
	MotorPWR(true);
}

void Servo::MotorPWR(bool enable)
{
	digitalWrite(MOTOR_RELAY, (enable) ? HIGH : LOW);
}

void Servo::Ctrl(void)
{
	PidPosition.Setparam(PIDPolohaP.Get(), 0);
	PidSpeed.Setparam(PIDRychlostP.Get(), PIDRychlostI.Get());
	PidPosition.Outrange(-MaxRychlost.Get(), MaxRychlost.Get(), -MinRychlost.Get(), MinRychlost.Get());

	PositionCtrl();
	SpeedCtrl();
}

void Servo::Run(void)
{

	ReadCurrent();
	ReadTemperature();

	int32_t DmdSpeed = PozadovanaRychlost.Get();

	if (DmdSpeed > 0)
	{
		encoder_lim_max.Check(sensor.debLimMax.Out());
		encoder_lim_min.Check(false);
		sensor.debLimMin.Reset();

		IsOverCurrentUp(AktualniProud_mA.Get());
		ovrl_down.Check(false);
		fast_ovrl_down.Check(false);

		if (Error::IsBlocked(MOVE_UP | MOVE_CTRL_BLOCK))
		{
			speedCtrlPWM = 0;
		}
	}
	else if (DmdSpeed < 0)
	{
		encoder_lim_min.Check(sensor.debLimMin.Out());
		encoder_lim_max.Check(false);
		sensor.debLimMax.Reset();

		IsOverCurrentDown(AktualniProud_mA.Get());
		ovrl_up.Check(false);
		fast_ovrl_up.Check(false);

		if (Error::IsBlocked(MOVE_DOWN | MOVE_CTRL_BLOCK))
		{
			speedCtrlPWM = 0;
		}
	}
	else
	{
		speedCtrlPWM = 0;
		ovrl_down.Check(false);
		fast_ovrl_down.Check(false);
		ovrl_up.Check(false);
		fast_ovrl_up.Check(false);
	}

	RizeniMotoru_PWM.Set(speedCtrlPWM);
	motor.Run(RizeniMotoru_PWM.Get());
}

void Servo::SpeedCtrl(void)
{
	int32_t ActSpeed = sensor.GetActSpeed();
	int32_t DmdSpeed = PozadovanaRychlost.Get();
	AktualniRychlost.Set(ActSpeed);
	int32_t err = (DmdSpeed - ActSpeed);

	if (Error::IsBlocked(MOVE_UP | MOVE_DOWN))
	{
		speedCtrlPWM = PidSpeed.Setout(0, 0);
	}
	else
	{
		speedCtrlPWM = PidSpeed.Evaluate(err);
	}
}

/*Regulace polohy serva*/
void Servo::PositionCtrl(void)
{
	static int16_t lastDemPos = 0;

	int32_t Err = PozadovanaPoloha_puls.Get() - AktualniPoloha_puls.Get();

	target_pos.Check((abs(Err) < 3) && !isStopped);

	if (Error::IsBlocked(MOVE_UP | MOVE_DOWN))
	{
		PozadovanaRychlost.Set(0);
		speedCtrlPWM = PidSpeed.Setout(0, 0);
	}
	else
	{
		PozadovanaRychlost.Set(PidPosition.Evaluate(Err));
	}

	no_move.Check(sensor.IsSteady() && (PozadovanaRychlost.Get() != 0));
}
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

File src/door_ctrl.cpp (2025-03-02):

/***********************************************************************
 * Filename: door_ctrl.cpp
 * Author: Pavel Kejik
 * Date: 2024-04-12
 * Description:
 *     Defines event processing functions for the finite state machine 
 *     in the DoorCtrl class.
 *
 ***********************************************************************/


#include <door_ctrl.h>
#include "led.h"
#include "servo.h"
#include "log.h"

#define TIME_SCHEDULE(_t_secs) ((uint32_t)((_t_secs) * 1000 / CONTROL_TASK_PERIOD_MS))

std::atomic<uint32_t> DoorCtrl::events;
uint32_t DoorCtrl::timer;
std::mutex DoorCtrl::events_mutex;
Debounce DoorCtrl::steady_move(5, 20);

extern Encoder encoder;
extern Servo servo;

const char *const cmd_source_txt[] = {
    "",
    "(Tlacitkem)",
    "(Osvetlenim)",
    "(Casem)",
    "(Modbus)",
    "(HTTP)",
    ""};

DoorState_t noaction()
{
    return NOSTATE;
}

DoorState_t init_open()
{
    SystemLog::PutLog("Start otevirani na doraz " + String(cmd_source_txt[PovelOd.Get()]), v_info);
    servo.ChangePosition(MAX_INIT_OPEN_INTERVAL_PULS);
    return OteviraniMax;
}

DoorState_t init_close()
{
    SystemLog::PutLog("Start zavirani na doraz " + String(cmd_source_txt[PovelOd.Get()]), v_info);
    servo.ChangePosition(-MAX_INIT_OPEN_INTERVAL_PULS);
    return ZaviraniMin;
}

DoorState_t closed()
{
    SystemLog::PutLog("Zavreno", v_info);
    servo.Stop();
    error_close.Clear();
    CasZavreni.Set(Now());
    return Zavreno;
}

DoorState_t opened()
{
    SystemLog::PutLog("Otevreno", v_info);
    servo.Stop();
    error_open.Clear();
    CasOtevreni.Set(Now());
    return Otevreno;
}

DoorState_t stop()
{
    SystemLog::PutLog("Stop", v_info);

    servo.Stop();

    if (DolniPoloha.Get() == Overen)
    {
        if (DoorCtrl::PosInRange(-TOL_CLOSE_POS_PLS, TOL_CLOSE_POS_PLS))
        {
            return closed();
        }
        else if (HorniPoloha.Get() == Overen)
        {
            if (DoorCtrl::PosInRange(Otevreno_puls.Get() - 2 * TOL_OPEN_POS_PLS, Otevreno_puls.Get() + TOL_OPEN_POS_PLS))
            {
                return opened();
            }
            else
            {

                return MeziPoloha;
            }
        }
    }

    return NeznaznamaPoloha;
}

DoorState_t break_close()
{
    // SystemLog::PutLog("Stop", v_info);

    servo.Stop();

    DoorCtrl::TimerStart(3);

    return StopZavirani;
}

DoorState_t break_open()
{
    // SystemLog::PutLog("Stop", v_info);

    servo.Stop();

    DoorCtrl::TimerStart(3);

    return StopOtevirani;
}

DoorState_t detect_open()
{
    uint16_t state = HorniPoloha.Get() + 1;
    Otevreno_puls.SetLimit(AktualniPoloha_puls.Get());

    servo.Stop();

    if (state < Overen)
    {
        if ((DolniPoloha.Get() == Overen) && DoorCtrl::PosInRange(MIN_OPEN_INTERVAL_PLS, MAX_OPEN_INTERVAL_PLS))
        {
            HorniPoloha.Set(Overen);
            return opened();
        }

        SystemLog::PutLog("Odjezd od horniho dorazu", v_info);

        HorniPoloha.Set(state);

        servo.ChangePosition(-RELEASE_POS);

        return UvolneniOtevirani;
    }
    else
    {
        HorniPoloha.Set(Overen);
        return opened();
    }
}

DoorState_t repeat_open()
{
    SystemLog::PutLog("Opakovani otevreni", v_info);
    servo.ChangePosition(MAX_INIT_OPEN_INTERVAL_PULS);
    return OteviraniMax;
}

DoorState_t detect_close()
{
    uint16_t state = DolniPoloha.Get() + 1;
    servo.Stop();
    if (state < Overen)
    {
        if ((HorniPoloha.Get() == Overen) && DoorCtrl::PosInRange((int16_t)Otevreno_puls.Get() - MAX_OPEN_INTERVAL_PLS, (int16_t)Otevreno_puls.Get() - MIN_OPEN_INTERVAL_PLS))
        {
            Otevreno_puls.SetLimit(Otevreno_puls.Get() - AktualniPoloha_puls.Get());
            encoder.SetPosition(0);
            DolniPoloha.Set(Overen);
            return closed();
        }

        SystemLog::PutLog("Odjezd od dolniho dorazu", v_info);

        DolniPoloha.Set(state);
        servo.ChangePosition(RELEASE_POS);

        return UvolneniZavirani;
    }
    else
    {
        DolniPoloha.Set(Overen);

        if (HorniPoloha.Get() == Overen)
        {
            Otevreno_puls.SetLimit(Otevreno_puls.Get() - AktualniPoloha_puls.Get());
        }

        encoder.SetPosition(0);

        return closed();
    }
}

DoorState_t repeat_close()
{
    SystemLog::PutLog("Opakovani zavreni", v_info);
    servo.ChangePosition(-MAX_INIT_OPEN_INTERVAL_PULS);
    return ZaviraniMin;
}

DoorState_t unable_open()
{
    servo.Stop();

    if (DoorCtrl::PosInRange(Otevreno_puls.Get() - 2 * TOL_OPEN_POS_PLS, Otevreno_puls.Get() + 2 * TOL_OPEN_POS_PLS))
    {
        return opened();
    }

    if (error_open.Check(true))
    {
        HorniPoloha.Set(Nedetekovan);
        DolniPoloha.Set(Nedetekovan);
        DoorCtrl::TimerStart(2);
        return ChybaDveri;
    }

    // servo.ChangePosition(-RELEASE_POS);

    DoorCtrl::TimerStart(3);

    return PreruseniOtevirani;
}

DoorState_t relay_off()
{
    servo.MotorPWR(false);
    return ChybaDveri;
}

DoorState_t relay_on()
{
    servo.MotorPWR(true);
    return stop();
}

DoorState_t to_close()
{
    if (DolniPoloha.Get() != Overen)
    {
        return init_close();
    }

    SystemLog::PutLog("Zavirani " + String(cmd_source_txt[PovelOd.Get()]), v_info);

    servo.SetPosition(-TOL_CLOSE_POS_PLS);
    return Zavirani;
}

DoorState_t close_to_min()
{
    if (AktualniPoloha_puls.Get() < -MAX_INIT_OPEN_INTERVAL_PULS)
    {
        SystemLog::PutLog("Nenalezen dolni doraz", v_error);
        servo.Stop();
        HorniPoloha.Set(Nedetekovan);
        DolniPoloha.Set(Nedetekovan);
        DoorCtrl::TimerStart(1);
        return ChybaDveri;
    }

    HorniPoloha.Set(Nedetekovan);
    DolniPoloha.Set(Nedetekovan);
    servo.ChangePosition(-RELEASE_POS);
    return NOSTATE;
}

DoorState_t unable_close()
{
    servo.Stop();

    if (error_close.Check(true))
    {
        HorniPoloha.Set(Nedetekovan);
        DolniPoloha.Set(Nedetekovan);
        DoorCtrl::TimerStart(1);
        return ChybaDveri;
    }

    // servo.ChangePosition(RELEASE_POS);

    DoorCtrl::TimerStart(3);

    return PreruseniZavirani;
}

DoorState_t repeat_to_min()
{
    servo.Stop();
    if (DoorCtrl::PosInRange(-TOL_CLOSE_POS_PLS, TOL_CLOSE_POS_PLS))
    {
        return closed();
    }

    encoder.SetPosition(0);
    servo.Stop();
    DolniPoloha.Set(Overen);
    HorniPoloha.Set(Nedetekovan);
    CasZavreni.Set(Now());
    return Zavreno;
}

DoorState_t to_open()
{
    if (HorniPoloha.Get() != Overen)
    {
        return init_open();
    }

    SystemLog::PutLog("Otevirani " + String(cmd_source_txt[PovelOd.Get()]), v_info);

    servo.SetPosition(Otevreno_puls.Get() + TOL_OPEN_POS_PLS);
    return Otevirani;
}

bool DoorCtrl::PosInRange(int16_t min_pos, int16_t max_pos)
{
    return AktualniPoloha_puls.Get() >= min_pos && AktualniPoloha_puls.Get() <= max_pos;
}
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

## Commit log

2025-03-02 Initial commit of chicken door project
    [custom_table.csv, slunce.ods]
2025-04-23 Publish 3D-print STLs & KiCad sources
    [dvirka.kicad_pcb, dvirka.kicad_sch, dvirka_cena.ods]
2025-05-16 Add support for AI egg counting camera
